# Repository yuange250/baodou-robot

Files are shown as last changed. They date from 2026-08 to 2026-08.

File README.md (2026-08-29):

# Brufik in One

Monorepo combining **Brufik hardware/firmware** and **opendesk-service backend**.

> The current Baodou robot runs the ESP32-to-Doubao Realtime direct firmware. See the Chinese [`firmware development and flashing guide`](docs/firmware-development-and-flashing.md) for the source map, local setup, Windows flashing, logs, smoke tests, and Coding Agent handoff notes.

| Directory | Description |
|---|---|
| [`hardware/`](hardware/) | ESP32S3 firmware, mechanical assets, PCB rebuild files, flash scripts |
| [`service/`](service/) | Voice backend: VAD → ASR → LLM → TTS, WebSocket `/asr_chat`, web console |

## Quick start

### 1. Backend (service)

```bash
cd service
cp .env.example .env
# Edit .env — set LLM_API_KEY
chmod +x start.sh
./start.sh
```

Web console: `http://<host>:5050/` · Device WS: `ws://<host>:9000/asr_chat`

See [`service/README.md`](service/README.md).

### 2. Firmware (hardware)

```bash
cd hardware
# Copy firmware/deskbot_local_config.example.h to the ignored
# firmware/deskbot_local_config.h, then fill in local values.
./flash_rom.sh all
```

See [`hardware/README.md`](hardware/README.md) and [`hardware/README_zh.md`](hardware/README_zh.md).

For direct Realtime firmware, local credentials, Windows flashing, and safe GitHub publishing, see
[`docs/local-config-and-github.md`](docs/local-config-and-github.md).

For the current firmware architecture and complete edit/build/flash workflow, see
[`docs/firmware-development-and-flashing.md`](docs/firmware-development-and-flashing.md).

## License

- **Hardware** ([`hardware/mechanical/`](hardware/mechanical/)): CERN-OHL-S-2.0
- **Firmware** ([`hardware/firmware/`](hardware/firmware/)): GPL-3.0
- **Service** ([`service/`](service/)): GPL-3.0

See respective `LICENSE` files in each subtree.

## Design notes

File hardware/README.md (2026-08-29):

# Brufik

[中文](README_zh.md) | English

**Hardware in this repository is under [CERN-OHL-S-2.0](mechanical/LICENSE); software is under [GPL-3.0](firmware/LICENSE).**

**Brufik** is an open-source deskbot on **Seeed XIAO ESP32S3 Sense**. Backend: [open-deskbot-service](https://github.com/OpenDeskBot/open-deskbot-service).

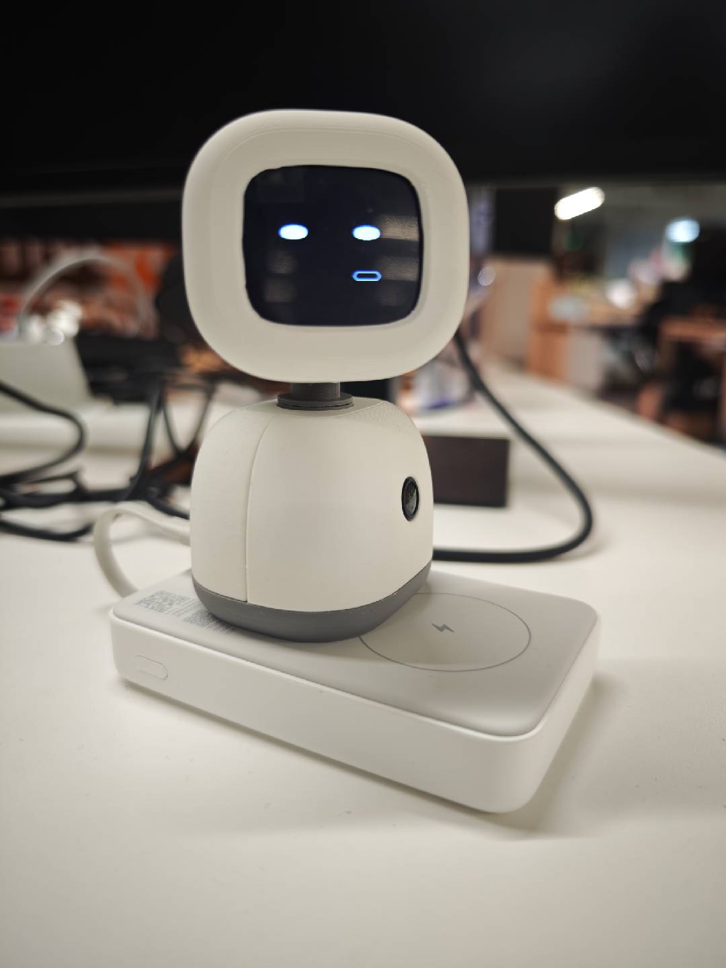
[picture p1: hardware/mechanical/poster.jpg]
Brufik deskbot — assembled unit


---

## 1. Out of the box

1. Copy [`firmware/deskbot_local_config.example.h`](firmware/deskbot_local_config.example.h) to the ignored `firmware/deskbot_local_config.h`, then set the local Wi-Fi values.
2. Power on — the device joins that WiFi and talks to your backend.
3. To use another SSID: power on the deskbot, join AP **`Deskbot_Rom`**, then open the address shown on the screen, usually **`http://192.168.4.1/`**. The onboarding page lets you pick or type your home WiFi and save it. For compile-time defaults, edit only the ignored `deskbot_local_config.h`.

---

## 2. Developers

The current Baodou unit uses the ESP32-to-Doubao Realtime direct firmware. On Windows, use `scripts/build_direct.ps1` so the ignored local Realtime/Ark credentials are injected at build time. See the Chinese [`firmware development and flashing guide`](../docs/firmware-development-and-flashing.md) for the complete workflow.

Create the ignored `firmware/deskbot_local_config.h` from its example, then:

```bash
./flash_rom.sh all
```

Deploy [open-deskbot-service](https://github.com/OpenDeskBot/open-deskbot-service). Firmware WebSocket: **`/asr_chat`**.

Optional debug: `http://<device-ip>/` for a local camera page.

---

## 3. DIY assembly

| Part | Notes | Search terms |
|---|---|---|
| MCU | Camera module + **onboard mic** on the Sense board (**no extra purchase**) | Seeed XIAO ESP32S3 **Sense** |
| Lens | For **OV2640**; **120°** wide angle; **same-plane** (not off-axis); **25 mm** length | `OV2640 lens 120° same plane 25mm` |
| LCD | 1.83" SPI ST7789 240×284 | Waveshare 1.83 LCD Rev2 |
| Servos | **Large + small**; pan = **2g micro servo**, tilt = larger servo | `2g servo`, `SG90` / `9g servo` |
| Amp | I2S | MAX98357A |
| Speaker | **2011** type | `2011 speaker`, `8Ω 2011` |
| Power | 5V ≥1A for servos | — |
| PCB | This repo includes an extension **PCB** for easier wiring; **hand-wiring without the PCB also works** | — |

### Assembly guide & reference photos

- **Step-by-step manual:** [`mechanical/说明书1.02PDF.pdf`](mechanical/说明书1.02PDF.pdf)
- **All parts laid out:** [`mechanical/parts-overview.png`](mechanical/parts-overview.png)
- **Core assembly done (shell not installed):** [`mechanical/assembly-without-shell.png`](mechanical/assembly-without-shell.png)
- **Side view without shell:** [`mechanical/assembly-side-no-shell.png`](mechanical/assembly-side-no-shell.png)

### Wiring (XIAO pad → device)

> Schematic **IO8 / IO3** = **GPIO numbers**, not silkscreen D8/D3.

| Device | Signals | XIAO pads |
|---|---|---|
| LCD SPI | MOSI/CLK/CS/DC | D10 / D8 / D1 / D2 |
| Servo X (pan) | PWM | **D9 / GPIO8** (2g; firmware applies 2:1 gain and tool-layer mirroring) |
| Servo Y (tilt) | PWM | **D3 / GPIO4** (large; lower logical values tilt upward) |
| MAX98357 | DIN/BCLK/LRC | D0 / D5 / D4 → 2011 speaker |
| Mic | PDM | **Onboard** (ESP32S3 Sense) |

Details: [`firmware/deskbot_config.h`](firmware/deskbot_config.h).

---

## License

| Scope | License | File |
|---|---|---|
| Hardware ([`mechanical/`](mechanical/)) | CERN-OHL-S-2.0 | [`mechanical/LICENSE`](mechanical/LICENSE) |
| Software ([`firmware/`](firmware/) etc.) | GNU GPL v3.0 | [`firmware/LICENSE`](firmware/LICENSE) |

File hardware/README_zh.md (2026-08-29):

# Brufik

[English](README.md)

**本仓库中的硬件设计部分遵循 [CERN-OHL-S-2.0](mechanical/LICENSE)，软件部分遵循 [GPL-3.0](firmware/LICENSE)。**

**Brufik** 是一款开源桌面机器人：Seeed XIAO ESP32S3 Sense + 屏 + 舵机 + 麦 + 喇叭。语音与画面走自建后台 [open-deskbot-service](https://github.com/OpenDeskBot/open-deskbot-service)。

Brufik 桌面机器人 — 组装完成实物

---

## 一、开箱即用

1. 复制 [`firmware/deskbot_local_config.example.h`](firmware/deskbot_local_config.example.h) 为被忽略的 `firmware/deskbot_local_config.h`，在其中填写本机 Wi‑Fi。
2. 给机器人上电，自动连上该 WiFi 并访问语音后台后即可使用（对话、表情、头部动作）。
3. 若需改用家里 WiFi：给小歪上电后按屏幕提示连接热点 **`Deskbot_Rom`**，浏览器打开屏幕上的地址（通常是 **`http://192.168.4.1/`**），按 onboarding 页面选择家里的 WiFi 并保存；编译期默认值只修改被忽略的 `deskbot_local_config.h`。

---

## 二、本地开发者

**需要：** USB、[PlatformIO](https://platformio.org/)，串口 `dialout` 权限。

当前包逗实机使用 ESP32 直连豆包 Realtime 版本。Windows 下应优先使用 `scripts/build_direct.ps1` 注入本地 Realtime/Ark 凭证；完整修改、烧录、日志和冒烟测试流程见 [`../docs/firmware-development-and-flashing.md`](../docs/firmware-development-and-flashing.md)。

烧录前从示例复制并编辑被忽略的 `firmware/deskbot_local_config.h`：`WIFI_DEFAULT_*`、`DESKBOT_WS_HOST`、`DESKBOT_WS_PORT`。

```bash
git clone https://github.com/OpenDeskBot/open-deskbot-hardware.git
cd open-deskbot-hardware
./flash_rom.sh all
```

| 命令 | 说明 |
|---|---|
| `./flash_rom.sh build` | 编译 |
| `./flash_rom.sh upload [端口]` | 烧录 |
| `./flash_rom.sh log [端口]` | 串口监视 |
| `./flash_rom.sh all [端口]` | 烧录 + 监视 |

后台部署见 [open-deskbot-service](https://github.com/OpenDeskBot/open-deskbot-service)。固件 WebSocket：**`/asr_chat`**。

调试：连上 WiFi 后浏览器可开 `http://<设备IP>/` 看摄像头（可选）。

---

## 三、自行组装

### 元器件与采购关键词

| 部件 | 说明 | 搜索关键词（淘宝/嘉立创等） |
|---|---|---|
| 主控 | 带摄像头模组 + **板载麦克风**（Sense 扩展板上，**无需另购**） | `Seeed XIAO ESP32S3 Sense`、`Seeed Studio XIAO ESP32S3 Sense` |
| 镜头 | **OV2640** 用；广角 **120°**；**同面**（勿买异面）；长度 **25 mm** | `OV2640 镜头 120度 同面 25mm` |
| 屏幕 | 1.83 寸 SPI，**ST7789** 240×284 | `微雪 1.83寸 LCD`、`Waveshare 1.83 LCD Rev2`、`ST7789 240x284` |
| 舵机 | **一大一小**：俯仰用大舵机，水平用 **2g 舵机** | `2g 舵机`、`微型舵机 2g`；大舵机可用 `SG90` / `9g 舵机` 等 |
| 功放 | I2S | `MAX98357A`、`MAX98357 模块` |
| 喇叭 | **2011** 腔体喇叭 | `喇叭 2011`、`2011 喇叭`、`8Ω 2011 扬声器` |
| 杜邦线 / 细线 | 信号与电源 | `杜邦线`、`硅胶线 26AWG` |
| 电源 | 5V 给舵机（≥1A），3.3V 给板子/屏 | `5V 1A 电源模块`、`USB 5V` |
| PCB | 本项目提供一块扩展 **PCB**，可简化接线；**不用 PCB 也可自行飞线焊接** | — |

### 组装说明与参考图

- **图文说明书：** [`mechanical/说明书1.02PDF.pdf`](mechanical/说明书1.02PDF.pdf)
- **零件全图：** [`mechanical/parts-overview.png`](mechanical/parts-overview.png)
- **基本组装完成（未装外壳）：** [`mechanical/assembly-without-shell.png`](mechanical/assembly-without-shell.png)
- **未装外壳侧面：** [`mechanical/assembly-side-no-shell.png`](mechanical/assembly-side-no-shell.png)

### 接线（XIAO 丝印 → 外设）

> 微雪图纸上的 **IO8 / IO3** 指 **ESP32 GPIO 号**，不是丝印 **D8 / D3**。

| 外设 | 信号 | 接 XIAO 焊盘 | 备注 |
|---|---|---|---|
| **LCD** | MOSI / SCK / CS / DC | **D10 / D8 / D1 / D2** | SPI |
| **舵机 左右 (X)** | PWM | **D9 / GPIO8** | 小 2g 舵机；当前固件含 2:1 增益与工具层镜像 |
| **舵机 上下 (Y)** | PWM | **D3 / GPIO4** | 大舵机；数值减小为抬头 |
| **MAX98357** | DIN / BCLK / LRC | **D0 / D5 / D4** | I2S → 2011 喇叭 |
| **麦克风** | PDM | **板载**（ESP32S3 Sense 主板上） | 无需外接 INMP441 |
| **舵机电源** | 5V / GND | 独立 5V≥1A | 与逻辑共地 |

引脚宏定义见 [`firmware/deskbot_config.h`](firmware/deskbot_config.h) 硬件段。组装完成后按第二节烧录、配网。

---

## 许可证

| 范围 | 协议 | 文件 |
|---|---|---|
| 硬件设计（[`mechanical/`](mechanical/)） | CERN-OHL-S-2.0 | [`mechanical/LICENSE`](mechanical/LICENSE) |
| 软件（[`firmware/`](firmware/) 等） | GNU GPL v3.0 | [`firmware/LICENSE`](firmware/LICENSE) |

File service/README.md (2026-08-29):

# opendesk-service

ESP32 桌面机器人后端：设备上传语音（可选摄像头），服务端完成 **VAD → ASR → LLM → TTS**，经 **pb** 协议下发 PCM、屏幕动画与舵机指令。

**License:** [GPL-3.0](LICENSE)

---

## 最快部署（3 步）

**环境：** Ubuntu 22.04 / 24.04（或 macOS / Windows Git Bash）、Python **3.11**、`ffmpeg`、可访问外网（首次下载模型与 pip 包）。

```bash
# 1. 系统依赖（Ubuntu）
sudo apt update
sudo apt install -y python3.11 python3.11-venv python3.11-dev ffmpeg curl git

# 2. 配置大模型 Key（必填）
cd opendesk-service
cp .env.example .env
# 编辑 .env，填写 LLM_API_KEY=sk-...

# 3. 一键启动（自动建 venv、下载模型、起主服务 + Web 控制台）
chmod +x start.sh
./start.sh
```

首次启动约需数分钟（ASR 模型约 900MB）。**第二次及以后**若 `.venv` 已完整，直接 `./start.sh` 会自动跳过 pip 安装；也可显式：

```bash
SKIP_SETUP=1 ./start.sh
# 或
FAST_START=1 ./start.sh
```

| 服务 | 地址 | 用途 |
|---|---|---|
| **Web 控制台** | `http://<本机IP>:5050/` | 注册登录、设备与 API Key、定时任务、记忆等 |
| **设备 WebSocket** | `ws://<本机IP>:9000/asr_chat?device_id=<id>&api_key=<key>` | ESP32 语音对话主链路 |

启动后终端会打印**免费体验 API Key** 路径：`data/.free_api_key`（前缀 `odk_free_`，每日 1GB 配额）。

---

## 快速使用

### 1. 打开控制台

浏览器访问 `http://<本机IP>:5050/` → **注册**账号 → 登录进入工作台。

### 2. 获取 API Key

**账号设置** 中创建 API Key，或直接使用首次启动生成的 `data/.free_api_key`。

### 3. 绑定设备

**我的设备** 中添加 `device_id`（与固件一致，如 `deskbot_e8f60a8cf9b0`）。后续管理定时任务、记忆、人脸档案时需先**选择设备**。

### 4. 连接设备对话

固件连接：

```
ws://<本机IP>:9000/asr_chat?device_id=<你的device_id>&api_key=<你的key>
```

说话后发送 `flush`，服务端识别 → 调用 LLM → TTS → pb 下行播放。

### 5. 无硬件时本地试跑

```bash
source .venv/bin/activate
python tools/test_client.py \
  --ws-url "ws://127.0.0.1:9000/asr_chat?device_id=deskbot_dev&api_key=<key>" \
  --input-wav demo_16k_mono.wav
```

WAV 须 **16 kHz / mono / s16le**。麦克风实时测试见 [tools/README.md](tools/README.md)。

### 6. 控制台常用功能

| 菜单 | 说明 |
|---|---|
| 工作台 | 用量概览与快捷入口 |
| 我的设备 | 绑定 / 切换 `device_id` |
| 定时任务 | 查看 LLM 创建的 cron 任务（北京时间），可删除 |
| 记忆 | 按设备管理长期记忆（注入 LLM） |
| 人脸识别 | 按设备查看人脸档案 |
| 用量看板 | 按 Key / 设备查看 ASR、人脸、LLM、TTS 字节统计 |
| 调试台 | 设备在线、LLM 试聊、豆包 TTS、流水线等 |

语音对话中，LLM 可通过工具创建定时提醒（`schedule_task`）、读写设备临时文件、联网搜索等，详见 [docs/SERVER.md](docs/SERVER.md)。

---

## 与 ESP32 的交互（概要）

单条 WebSocket：`/asr_chat?device_id=<id>&api_key=<key>`（也可用 Header `X-API-Key`）。上行、下行均采用 **「JSON + 紧随一条 binary」**，长度由 **`next_bin_len`** 声明，**不用 base64**。

```
┌──────── ESP32 ────────┐                    ┌──── deskbot-server ────┐
│ 麦克风 Opus/PCM       │  audio + binary    │ VAD → FunASR → 文本     │
│ 可选 JPEG             │  camera_frame      │ → DashScope LLM + tools │
│ flush / pb_ack        │ ─────────────────► │ → 豆包 TTS + 音素口型   │
│                       │                    │ → 组 pb + PCM           │
│ 播放 PCM + 画屏       │  pb_* + binary     │                         │
│ 舵机 / 音量 / 帧率    │ ◄───────────────── │                         │
└───────────────────────┘                    └─────────────────────────┘
```

TTS 使用火山引擎豆包（`tts.provider: doubao`），凭证配置见 `.env` 与调试台「TTS 调试」。

### 上行（设备 → 服务端）

| JSON `type` | binary | 说明 |
|---|---|---|
| `audio` + `next_bin_len` | Opus 或 PCM | 语音流；段结束发 `flush` 触发识别与回复 |
| `camera_frame` + `next_bin_len` | JPEG | 可选；人脸检测与调试预览 |
| `pb_ack` | 无 | 播放缓冲回压 |
| `ping` | 无 | 保活 |

### 下行（服务端 → 设备）

默认 **`asr_chat_device_pb_only: true`**：只处理 **`pb_start` / `pb_chunk` / `pb_end` / `pb_single`**，以及紧随的 **s16le PCM**（24 kHz mono）。

完整字段见 **[docs/esp32_pb_protocol.md](docs/esp32_pb_protocol.md)**。

### 固件要点

1. URL 必须带稳定 **`device_id`** 与有效 **`api_key`**。
2. JSON 与 binary **严格成对、顺序发送**。
3. 周期性 **`pb_ack`** 做播放回压。

---

## 数据与目录

| 路径 | 说明 |
|---|---|
| `data/opendesk.db` | 用户、API Key、设备绑定、定时任务（SQLite） |
| `data/.free_api_key` | 免费体验 Key（勿提交 Git） |
| `data/device/{device_id}/` | 按设备隔离的配置、session、记忆等（**不入 Git**） |
| `data/llm_system.txt` | 全局 LLM 人设模板（新设备首次使用时复制） |

---

## 文档索引

| 文档 | 内容 |
|---|---|
| [docs/api_interfaces.md](docs/api_interfaces.md) | Web 控制台、deskbot 设备服务、TTS 侧车接口清单 |
| [docs/esp32_pb_protocol.md](docs/esp32_pb_protocol.md) | ESP32 通信、鉴权、pb 协议 |
| [docs/SERVER.md](docs/SERVER.md) | 主服务 API、配置、LLM 工具 |
| [docs/ARCHITECTURE.md](docs/ARCHITECTURE.md) | 代码分层与模块 |
| [tools/README.md](tools/README.md) | 本地联调脚本 |
| [docs/README.md](docs/README.md) | 文档目录 |

[CONTRIBUTING.md](CONTRIBUTING.md) · [SECURITY.md](SECURITY.md)

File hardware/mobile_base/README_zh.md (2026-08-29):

# Brufik × N3 移动底座 Rev 0.1

这套设计让现有 Brufik 上半身保持不动，在下方增加淘宝 N3 三轮全向底盘。
新增控制板独立负责三只 N20 电机、触摸输入和 5V 上半身供电，通过 UART 与
现有主板通信。

## 目录

- `mechanical/`：参数化外壳、转接座、触摸片支架和孔位验证片。
- `pcb/`：KiCad 4 层底盘控制板、BOM、接口表与嘉立创生产文件。

## 先做什么

1. 先打印 `mechanical/export/N3_58x49_fit_jig_v0_1.stl`。
2. 到货后确认 58 × 49 mm 孔位以及三个轮心到中心的距离。
3. 用限流电源手焊验证一块 PCB，再打印整套上盖。
4. 6V N20 初次测试时把最大 PWM 限为 70%，并让 J2 总开关随手可断电。

## 设计边界

- 外壳按卖家公布的 160 × 150 × 65 mm 整机尺寸和 50 mm 全向轮建立。
- 卖家没有给轮心精确坐标；当前模型暂按 57 mm 轮心半径，必须由实物复核。
- PCB 为 92 × 74 mm，安装孔仍是 N3 标准 58 × 49 mm。
- PCB 已通过 KiCad DRC（0 违规、0 未连接）；Gerber 可用于裸板试产。
- PCBA 仍需要在嘉立创逐项确认 LCSC 料号和贴装方向。

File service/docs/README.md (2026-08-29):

# 文档目录

本仓库文档与当前实现对齐，入口为根目录 [README.md](../README.md)。

## 协议与设备

| 文档 | 内容 |
|---|---|
| [api_interfaces.md](./api_interfaces.md) | Web 控制台、deskbot 设备服务、TTS 侧车接口清单 |
| [esp32_pb_protocol.md](./esp32_pb_protocol.md) | ESP32 WebSocket 鉴权、上行 / 下行、pb v2 图元与表情 |

## 服务

| 文档 | 内容 |
|---|---|
| [SERVER.md](./SERVER.md) | 主服务：端口、控制台、LLM 工具、豆包 TTS 配置 |
| [ARCHITECTURE.md](./ARCHITECTURE.md) | 代码分层、对话与定时任务链路 |

## 联调工具

| 文档 | 内容 |
|---|---|
| [../tools/README.md](../tools/README.md) | WAV / 麦克风 / 相机测试客户端 |

## 协作与安全

| 文档 | 内容 |
|---|---|
| [../CONTRIBUTING.md](../CONTRIBUTING.md) | 贡献流程与测试 |
| [../SECURITY.md](../SECURITY.md) | 密钥、鉴权与部署安全 |

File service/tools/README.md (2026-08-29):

# 本地调试工具

在 `.venv` 激活后运行。WebSocket URL **须带 `device_id` 与 `api_key`**（可用 `data/.free_api_key` 中的免费 Key）。

```bash
source .venv/bin/activate
KEY="odk_free_xxxx"   # 替换为实际 Key

# 推送 wav 测 /asr_chat 全链路
python tools/test_client.py \
  --ws-url "ws://127.0.0.1:9000/asr_chat?device_id=deskbot_dev&api_key=${KEY}" \
  --input-wav demo_16k_mono.wav

# 本机麦克风
python tools/live_mic_client.py \
  --ws-url "ws://127.0.0.1:9000/asr_chat?device_id=deskbot_dev&api_key=${KEY}"

# 推图片测 camera_frame
python tools/camera_test_client.py \
  --ws-url "ws://127.0.0.1:9000/asr_chat?device_id=deskbot_dev&api_key=${KEY}" \
  --image-dir ./samples

# 设备-服务端网络连通性 / 并发 / PB 延迟（须真实设备在线）
python tools/network_connectivity_test.py \
  --device-id deskbot_e8f60a8cf9b0 \
  --base-url http://127.0.0.1:9000 \
  --concurrent-sec 20
```

WAV 须 **16 kHz / mono / s16le**。

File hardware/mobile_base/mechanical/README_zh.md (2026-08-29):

# Brufik × N3 移动底座外壳

本目录是针对淘宝 N3 三轮全向底盘的参数化机械设计。设计目标是保留现有
Brufik 机身和内部机构，只在下方增加可拆卸移动底座。

## 设计组成

- `N3_upper_cowl_v0_1`：覆盖上层亚克力板和电子仓的低矮外壳，带三个轮拱。
- `Brufik_to_N3_adapter_v0_1`：现有机身与 N3 的转接座。
- `N3_58x49_fit_jig_v0_1`：先打印的孔位验证片。
- `Head_touch_electrode_holder_v0_1`：粘在头壳内侧的触摸电极固定片。
- `Brufik_N3_mobile_base_v0_1.step`：装配参考模型。

## 打印与验证顺序

1. 先打印 `N3_58x49_fit_jig_v0_1.stl`，确认卖家所说的 58 × 49 mm 孔距。
2. 用 M3 螺钉检查四个长圆孔均可自由通过。
3. 核对三个轮心到中心的实际距离。脚本暂按 57 mm 设计。
4. 孔距正确后再打印转接座和上盖。

推荐参数：0.4 mm 喷嘴、0.20 mm 层高、4 道墙、20% Gyroid 填充。转接座和
孔位片不需要支撑；上盖大平面朝向打印板，轮拱区域使用树状支撑。

## 当前需要实物复核的参数

卖家图片只给出了整体尺寸和标准孔位，没有给出三个轮心坐标。所有待复核尺寸
集中在 `generate_cad.py` 的 `N3Dimensions` 中，底盘到货后只需修改参数并重新
执行脚本即可生成全部 STL/STEP。

生成命令：

```powershell
$env:PYTHONPATH='C:\Users\Chen\AppData\Local\Temp\codex-brufik-cadquery'
python .\generate_cad.py
```

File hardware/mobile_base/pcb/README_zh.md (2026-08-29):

# Brufik N3 移动底盘控制板

这是与现有 Brufik 主板并行工作的底盘副板，不替换已经调通的屏幕、音频、
摄像头和舵机主板。

## 主要功能

- XIAO ESP32-C3 独立执行三轮全向运动控制。
- 两颗 DRV8833 驱动三只 N20 电机。
- 三路 0.20Ω 电流采样电阻将斩波电流设在约 1A。
- 2S 受保护锂电池输入，5A 自恢复保险和外接总开关。
- TPS54302 产生 5V/3A，给现有机器人上半身供电。
- 一个四针上半身接口：5V、GND、UART TX、UART RX。
- 一个三针数字触摸接口。
- J2 外接自锁总开关，既是电源开关也是机械急停。

## 供电边界

电机 VM 直接来自 2S 电池。对于套件内常见的 6V N20，固件必须把最大 PWM
限制在 70%，并保留约 1A 的硬件限流。若卖家提供 9V N20，则可将最大 PWM
上调，但仍需测量堵转电流和驱动温度。

J2 必须连接自锁开关；台架调试时可以暂时用跳线帽短接。连接 USB 给底盘 XIAO
刷机前，先关闭电池总开关并拔掉 J6 上半身接口，避免 USB 5V、板载 5V 与上半身
USB 互相反向供电。

## PCB 规格

- 外形：92 × 74 mm，四角倒角。
- 安装孔：58 × 49 mm，M3。
- 4 层板：F.Cu 信号/功率、In1.GND、In2.VBAT（局部 SLEEP 走线）、B.Cu 信号。
- 推荐：1.6 mm、1 oz 外层/内层铜、HASL-LF 或 ENIG。

## 当前验证状态

- KiCad 10 DRC：0 违规。
- 未连接网络：0。
- `production/BrufikMobileBase_gerbers.zip` 可直接用于裸板下单。
- BOM 与贴片坐标已经导出，但不是一键 PCBA 文件；下贴片单前仍需在嘉立创
  核对每个 LCSC 编号、封装方向和缺料替代。

## 下单前仍需实物确认

这是根据卖家尺寸和原厂数据手册生成的 Rev 0.1 工程。底盘到货后，仍需确认：

1. N20 电机额定电压与堵转电流；
2. 58 × 49 mm 孔距；
3. 电池包是否自带 2S BMS；
4. 嘉立创元件库中的 DRV8833PWPR、TPS54302DDCR 和连接器封装。

裸板可以按生产包下单；首次只下 5 片并手焊 1 片验证。开关降压部分应按 TI
推荐布局复核输入电容、SW 节点、L1 和输出电容，通电前先用限流电源测试。

生成与检查：

```powershell
& 'C:\Users\Chen\AppData\Local\Programs\KiCad\10.0\bin\python.exe' .\generate_pcb.py
powershell.exe -NoProfile -ExecutionPolicy Bypass -File .\export_production.ps1
```

原厂参考：

- TI DRV8833 datasheet: https://www.ti.com/lit/ds/symlink/drv8833.pdf
- TI TPS54302 datasheet: https://www.ti.com/lit/ds/symlink/tps54302.pdf

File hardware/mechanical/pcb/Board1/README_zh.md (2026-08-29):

# Board1 原理图（重建版）

本目录提供 **Brufik 转接板 Board1 / PCB1** 的连接关系重建文件。  
原始 PCB 在嘉立创 EDA 中设计（BOM 导出者 `jlceda`，2026-06-12），但仓库目前只包含 BOM 与贴片坐标，**未包含原始 `.epro` 工程**。

## 文件说明

| 文件 | 用途 |
|---|---|
| **`Board1_kicad.zip`** | **可直接导入嘉立创 EDA 的 KiCad 工程压缩包（推荐）** |
| `Board1.kicad_pro` / `.kicad_sch` / `.kicad_pcb` | KiCad 工程（**v2.1 PCB 已含元件布局**） |
| `generate_kicad.py` | 重新生成上述 KiCad 文件的脚本 |
| `Board1_schematic.svg` | 可视化原理图/框图，可导入嘉立创 EDA 作参考底图 |
| `Board1_pinout.csv` | 逐引脚网表，手工画原理图时对照 |
| `Board1.net` | KiCad 风格网表，可用于核对网络 |
| `../BOM_Board1_PCB1_2026-06-12.xlsx` | 官方 BOM（LCSC 料号/封装） |
| `../PickAndPlace_PCB1_2026_06_12.xlsx` | 官方贴片坐标 |

## 导入嘉立创 EDA 的推荐步骤

### 方案 A：你有原始嘉立创账号工程（最佳）

若 PCB 是你或团队在嘉立创 EDA 里画的：

1. 登录 [嘉立创EDA 标准版](https://lceda.cn/editor) 或 [专业版](https://pro.lceda.cn/editor)
2. 打开对应工程 → **个人中心 → 工程 → 工程高级设置 → 下载工程**
3. 得到 `.epro` 或 JSON 压缩包，直接在编辑器中打开即可

> BOM 里的 `docProps/custom.xml` 含工程指纹，说明原始文件来自嘉立创 EDA。

### 方案 B：在嘉立创 EDA 中按 BOM 重建原理图（本仓库无原工程时）

转接板元件少，建议 **30–60 分钟手工重建**，比格式转换更可靠。

#### 1. 新建工程

- 标准版：<https://lceda.cn/editor> → 新建 → 原理图 + PCB
- 专业版：<https://pro.lceda.cn/editor> → 新建工程

#### 2. 放置元件（与 BOM 一致）

在 LCSC 库中搜索并放置：

| 位号 | 型号/关键词 | 封装 |
|---|---|---|
| USB1 | `TYPE-C 6P(073)` / C668623 | TYPE-C-SMD_TYPE-C-6P-073 |
| 1K1, 5.1k | `0805 5.1k` / C27834 | R0805 |
| H3, H4 | `PZ254V-11-07P` / C492406 | HDR-TH_7P-P2.54-V-M |
| vin | `PZ254R-11-07P` / C492415 | HDR-TH_7P-P2.54-H-M-W10.4 |
| vcc | `ZX-MX1.25-8PLT` / C19272385 | CONN-SMD_8P-P1.25 |
| X舵机 | `PZ254R-11-03P` / C492411 | HDR-TH_3P-P2.54-H-M-W10.4 |
| Y舵机 | `PZ254V-11-03P` / C2937625 | HDR-TH_3P-P2.54-V-M |

也可：**文件 → 导入 → BOM**，直接导入 `BOM_Board1_PCB1_2026-06-12.xlsx`（若编辑器支持），再补连线。

#### 3. 按网表连线

打开 `Board1_pinout.csv`，逐网络连接。核心网络：

```
+5V:  USB1.VBUS → H4-5V → X舵机-2 → Y舵机-2
GND:  所有连接器 GND、CC 下拉电阻另一端
+3V3: H4-3V3 → vin-1 → vcc-1
I2S:  H3-D0/D5/D4 → vin-3/4/5
LCD:  H3-D1/D2 + H4-D8/D10 → vcc-5/6/4/3
舵机: H4-D6/D7 → Y舵机-3 / X舵机-3
喇叭: vcc-7/8 → vin-6/7 → MAX98357 模块
USB CC: CC1→1K1→GND, CC2→5.1k→GND
```

#### 4. 导入参考底图（可选）

- **标准版**：PCB 编辑器 → **工具 → 导入图像** → 选 `Board1_schematic.svg`，缩小透明度作对照
- **专业版**：PCB → **放置 → 图片** 或导入 DXF/SVG 参考层

#### 5. 原理图转 PCB

- 菜单：**设计 → 原理图转 PCB**
- 检查封装映射无误后生成 PCB

#### 6. 对齐已有贴片坐标

若需与官方 PCB 布局一致：

1. PCB 中 **文件 → 导入 → 坐标文件**（或手动对照）
2. 导入 `PickAndPlace_PCB1_2026_06_12.xlsx`
3. 逐位号核对 Mid X/Y、Rotation、Layer

#### 7. 设计规则检查

- 原理图：**设计 → 电气规则检查 (ERC)**
- PCB：**设计 → 设计规则检查 (DRC)**
- 对照 `Board1_pinout.csv` 与 `firmware/deskbot_config.h` 引脚定义

### 方案 C：导入本目录 KiCad 工程（最快）

已生成完整 KiCad 工程，可直接导入嘉立创 EDA：

#### 嘉立创 EDA 标准版

1. 打开 <https://lceda.cn/editor>
2. **文件 → 导入 → KiCad**
3. 选择 `Board1_kicad.zip`（或整个 `Board1/` 文件夹打 ZIP）
4. 等待解析完成，打开原理图核对网络
5. 打开 **PCB 编辑器** — v2.1 已按官方 PickAndPlace 放置 9 个元件（约 36×44mm 板框）
6. 若 PCB 仍为空，重新导入最新 `Board1_kicad.zip`（勿用旧版）
7. **设计 → 更新 PCB** 同步原理图网络后 **自行布线**（无官方走线）

#### 嘉立创 EDA 专业版

1. 打开 <https://pro.lceda.cn/editor>
2. **文件 → 导入 → KiCad**（或使用 **格式转换器**）
3. 选择 `Board1_kicad.zip`
4. 核对符号/网络，打开 PCB 查看元件布局（9 个封装 + 板框）
5. **更新 PCB** 同步网络，再布线

#### 用 KiCad 打开（可选）

1. 安装 [KiCad 8+](https://www.kicad.org/download/)
2. 打开 `Board1.kicad_pro`
3. 若提示库缺失，可忽略（符号已内嵌在 `.kicad_sch`）
4. 修改后 **文件 → 归档工程** 再导入嘉立创

> 本 KiCad 工程为 **BOM + 固件引脚反推重建**，非官方 Gerber 源文件。导入后请对照 `Board1_pinout.csv` 做 ERC，并将连接器封装替换为 LCSC 官方 footprint（C668623 等）。

## XIAO 插座引脚对照

```
H3 (7P):  D0  D1  D2  D3  D4  D5  GND
H4 (7P):  5V  3V3 D6  D7  D8  D9  D10
```

丝印与 GPIO 对应见 `firmware/deskbot_config.h`：

- D0=GPIO1 (I2S DIN)
- D1=GPIO2 (LCD CS)
- D2=GPIO3 (LCD DC)
- D4=GPIO5 (I2S LRC)
- D5=GPIO6 (I2S BCLK)
- D6=GPIO43 (Y 舵机)
- D7=GPIO44 (X 舵机)
- D8=GPIO7 (LCD SCK)
- D10=GPIO9 (LCD MOSI)

## 注意事项

1. **SPK+/SPK- 引脚顺序**：本重建依据说明书「头部喇叭线 → 转接板 → 功放板」走线推断；若你手上有已装好的板子，用万用表通断档核对 vcc-7/8 与 vin-6/7 最稳妥。
2. **D3、D9** 在本板未引出到外部连接器，原理图中可悬空或加 NC 标记。
3. 若需下单 PCB，可直接使用官方 Gerber（如后续仓库补充）；本重建版仅供原理图编辑/学习，**不保证与量产 Gerber 逐线一致**。

## 相关文档

- 接线表：[`README_zh.md`](../../../README_zh.md) 第三节
- 组装说明：[`mechanical/说明书1.02PDF.pdf`](../../说明书1.02PDF.pdf)

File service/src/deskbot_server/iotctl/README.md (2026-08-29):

# miot-ctl

轻量米家 IoT 命令行工具，基于 [miloco-miot](https://github.com/XiaoMi/xiaomi-miloco) SDK，**不依赖 Miloco 服务端**。

安装体积约 **50–80 MB**（仅 HTTP 控制所需依赖，无 opencv/onnx/感知模型）。

## 快速开始

```bash
# 1. 安装（自动下载 wheel + 创建虚拟环境）
bash install.sh

# 2. 绑定小米账号
./miot-ctl auth bind

# 授权后浏览器会跳到 https://127.0.0.1/?code=...&state=...
# 页面显示「无法访问」是正常的，复制地址栏完整 URL 执行：
./miot-ctl auth authorize "https://127.0.0.1/?code=...&state=..."

# 3. 列出设备
./miot-ctl device list

# 4. 查看设备能力
./miot-ctl device spec <did>

# 5. 控制设备
./miot-ctl device set <did> on true
./miot-ctl device set <did> brightness 60
./miot-ctl device props <did> brightness

# 6. 调用动作（如音箱播报）
./miot-ctl device action <did> play-text "你好"
```

## 目录结构

```
iotctl/
├── install.sh          # 一键安装
├── miot-ctl            # 启动脚本
├── requirements.txt    # 最小 Python 依赖
├── miot_ctl/           # 工具源码
├── wheels/             # install.sh 下载的 SDK wheel
└── .venv/              # 虚拟环境（install.sh 创建，本地生成）
```

**运行时数据（含 token）不入库**，默认写入：

```
service/data/miot-cli/          # 独立 CLI（auth bind 等）
service/data/device/{id}/miot/  # deskbot 网站 / LLM 按设备绑定
```

上述目录已在 `service/.gitignore` 中忽略，**禁止**提交 `auth.json` 等敏感文件。

## 拷贝到其他机器

整个 `miot-ctl/` 目录可以直接复制走。到新机器后：

```bash
cd miot-ctl
bash install.sh    # 若已带 wheels/ 和 .venv 可跳过，直接 ./miot-ctl
./miot-ctl auth status
```

迁移 CLI 登录态时拷贝 `service/data/miot-cli/`，或在新机器重新 `auth bind`。

也可自定义数据目录：

```bash
export MIOT_CTL_HOME=/path/to/your/data
./miot-ctl device list
```

## 命令参考

### 账号

| 命令 | 说明 |
|---|---|
| `auth bind` | 浏览器授权绑定 |
| `auth authorize <base64>` | 非交互提交授权码 |
| `auth status` | 查看绑定状态 |
| `auth unbind` | 解绑 |

### 设备

| 命令 | 说明 |
|---|---|
| `device list [--online] [--json]` | 设备列表 |
| `device get <did>` | 设备详情 |
| `device spec <did>` | 能力列表 |
| `device set <did> <key> <value>` | 写属性 |
| `device props <did> [key...]` | 读属性 |
| `device action <did> <key> [args...]` | 调用动作 |

`key` 支持：
- `type_name`：如 `on`、`brightness`、`color-temperature`
- `prop.{siid}.{piid}` / `action.{siid}.{aiid}`

`value` 自动推断类型：`true/false/on/off` → 布尔，纯数字 → 数值，其余 → 字符串。

### 场景

| 命令 | 说明 |
|---|---|
| `scene list` | 列出手动场景 |
| `scene run <scene_id>` | 触发场景 |

## 手动安装 wheel

若 `install.sh` 下载失败，可手动放置 wheel：

```bash
# 从 GitHub Release 下载对应平台 wheel，例如：
# miloco_miot-2026.7.3-py3-none-manylinux_2_28_x86_64.whl
mkdir -p wheels
cp /path/to/miloco_miot-*.whl wheels/
bash install.sh
```

## 许可

基于 Xiaomi Miloco / miloco-miot SDK，**仅限非商业用途**。详见上游 [LICENSE.md](https://github.com/XiaoMi/xiaomi-miloco/blob/main/LICENSE.md)。

## 故障排查

| 现象 | 处理 |
|---|---|
| `未绑定小米账号` | 运行 `auth bind` |
| `state 不匹配` | 重新 `auth bind`，不要复用旧授权码 |
| `设备 spec 中未找到` | 先 `device spec <did>` 查正确 key |
| 控制成功但设备无反应 | 看返回 JSON 中 `code` 负值和 `code_msg` |
| 安装慢 | 设置 `export UV_INDEX_URL=https://pypi.tuna.tsinghua.edu.cn/simple` |

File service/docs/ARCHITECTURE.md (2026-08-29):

# deskbot-server 架构（概要）

分层：**ws / web**（协议入口）→ **application**（用例）→ **core**（端口 Protocol）← **infrastructure**（ASR / LLM / TTS 实现）。**pb**、**vision** 不依赖 ws。

## 主链路（语音对话）

```
/asr_chat
  → VAD + FunASR（ChatService.asr）
  → run_chat_turn
      → ensure_active_session（按 device 加载历史）
      → complete_llm_with_tool_loop（多轮 tools，最多 8 轮）
      → TTS phoneme 分片
      → pb.wire 组包
      → DownlinkPort.send_pb_wire
```

摄像头：`camera_frame` + JPEG → `camera_jpeg_pipeline` → 调试订阅 / 人脸跟踪 / 舵机跟随。

## 定时任务

```
ScheduledTaskScheduler（60s 轮询）
  → claim_due_tasks（SQLite scheduled_tasks，东八区 cron）
  → run_chat_turn（reuse_session_id，强制 TTS 提醒）
  → finish_scheduled_task
```

任务由 LLM `schedule_task` 工具创建；**不由服务端从用户话术正则推断**。

## 模块一览

| 目录 / 模块 | 职责 |
|---|---|
| `ws/` | WebSocket 路由、`AsrChatHub`、pb 下行队列、API Key 门禁 |
| `web/` | Flask 控制台（`app_bp` 设备/任务/记忆/人脸，`debug_bp` 调试） |
| `auth/` | 用户注册登录、API Key、设备绑定 |
| `db/` | SQLAlchemy 模型（User、ApiKey、Device、ScheduledTask、UsageDaily） |
| `application/chat_flow.py` | 单轮对话编排（LLM + TTS + pb） |
| `application/llm_tool_loop.py` | LLM 多轮 tool-call |
| `application/llm_tool_runner.py` | 执行 `tools` 指令 |
| `application/scheduled_task_scheduler.py` | 到期任务调度 |
| `scheduled_task_service.py` | cron CRUD、claim / finish |
| `session_store.py` | `data/device/{id}/session/*.json` |
| `device_data.py` | 按设备路径解析配置模板 |
| `memory_store.py` | 长期记忆（全局或设备级 JSON） |
| `pb/` | 表情、口型、舵机、wire 组包 |
| `vision/` | 人脸检测、embedding、跟随 |

## WebSocket

| 路径 | 生产必需 |
|---|---|
| `/asr_chat?device_id=&api_key=` | 是 |
| `/camera_view`、`/device_pipeline` | 否（调试） |

单进程 asyncio；`ChatService`（含 FunASR）全进程共享。重 CPU 走 `asyncio.to_thread`；`config.yaml` 的 `max_concurrent_asr` / `max_concurrent_face_infer` 限流。

## 装配（`main.py`）

```
init_database()
build_chat_service()
AsrChatHub + ScheduledTaskScheduler.start()
websockets.serve(:9000)
```

Web 控制台独立进程：`python -m deskbot_server.web`（`:5050`，`start.sh` 默认拉起）。

## 测试

```bash
source .venv/bin/activate
pytest tests/ -q
```

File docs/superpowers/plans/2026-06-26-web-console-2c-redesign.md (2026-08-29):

# Web 控制台 2C 化改造 Implementation Plan

> **For agentic workers:** REQUIRED SUB-SKILL: Use superpowers:subagent-driven-development (recommended) or superpowers:executing-plans to implement this plan task-by-task. Steps use checkbox (`- [ ]`) syntax for tracking.

**Goal:** 在不改动核心管线/协议/固件的前提下，为 deskbot-server 增加一套消费级（2C）Web 外壳，把「表情」「声音」做成两个核心可玩页面，并把记忆/提醒/人/设备重新包装、把开发者功能收进「高级」。

**Architecture:** 纯前端为主。新增一个 `app2c_bp` 蓝图（仅渲染模板）+ 消费级母版 `base_2c.html` + 主题 `theme_2c.css`，页面用内联 Vue 调用**已存在**的 JSON 接口（`/api/doubao_tts/*`、`/api/face_expr_scenes`、`/app/api/*`）。后端 Phase 1 零新增；Phase 2 可选新增一个极小的 per-device 情绪→场景映射 store。

**Tech Stack:** Flask 3 + Jinja2 + 内联 Vue 3（CDN/vendored）+ 原生 CSS；图标内联 Lucide SVG；pytest。

参考来源：
- 设计 spec：`docs/superpowers/specs/2026-06-26-web-console-2c-redesign-design.md`
- 视觉/标记来源（真实可复制）：`web控制台-2C-原型.html`（仓库根目录）
- 既有测试风格：`service/deskbot-server/tests/test_endpoint_auth.py`

> 所有路径以 `service/deskbot-server/` 为根，除非另写明（如根目录的原型 HTML）。

---

## File Structure

新建：
- `src/deskbot_server/web/static/theme_2c.css` — 消费级主题（从原型 `<style>` 移植）。
- `src/deskbot_server/web/templates/base_2c.html` — 侧边栏外壳 + Lucide 图标宏 + `{% block content %}`。
- `src/deskbot_server/web/templates/app2c/home.html` — 首页「家」。
- `src/deskbot_server/web/templates/app2c/voice.html` — 声音（调既有 `/api/doubao_tts/*`）。
- `src/deskbot_server/web/templates/app2c/expr.html` — 表情（调既有 `/api/face_expr_scenes`）。
- `src/deskbot_server/web/templates/app2c/memories.html` — 它记得的事（调 `/app/api/memories`）。
- `src/deskbot_server/web/templates/app2c/reminders.html` — 提醒（调 `/app/api/scheduled-tasks`）。
- `src/deskbot_server/web/templates/app2c/people.html` — 认识的人（调 `/app/api/face-profiles`）。
- `src/deskbot_server/web/templates/app2c/devices.html` — 我的设备（调 `/app/api/devices`）。
- `src/deskbot_server/web/templates/app2c/advanced.html` — 高级 hub（链接既有页面）。
- `src/deskbot_server/web/blueprints/app2c_bp.py` — 仅渲染上述模板的蓝图。
- `tests/test_app2c_pages.py` — 路由鉴权 + 200 烟雾测试。

修改：
- `src/deskbot_server/web/app.py` — 注册 `app2c_bp`；登录后落地页指向 `/home`。

Phase 2（可选）新建：
- `src/deskbot_server/emotion_expr_map_store.py` — per-device 情绪→场景映射 store。
- `tests/test_emotion_expr_map_store.py` — store 单测。
- 在 `app2c_bp.py` 增加 `GET/POST /api/emotion_expr_map`。
- `tests/test_emotion_expr_map_api.py` — 接口测试。

---

## Phase 0 — 外壳与蓝图

### Task 1: 消费级主题 theme_2c.css

**Files:**
- Create: `src/deskbot_server/web/static/theme_2c.css`

- [ ] **Step 1: 从原型移植样式**

打开仓库根目录 `web控制台-2C-原型.html`，复制其 `<style>…</style>` 标签**内部**的全部 CSS，原样粘贴到 `theme_2c.css`。该 CSS 已包含 `.app/.side/.navi/.stage/.hero/.mini/.vgrid/.vcard/.maprow/.thumb/.toast` 等全部类，且使用 `:root` 变量，无需改动。

- [ ] **Step 2: 校验文件非空且含关键类**

Run: `grep -c -E '\.side|\.navi|\.vgrid|\.thumb' src/deskbot_server/web/static/theme_2c.css`
Expected: 输出 ≥ 4

- [ ] **Step 3: Commit**

```bash
git add src/deskbot_server/web/static/theme_2c.css
git commit -m "feat(web2c): add consumer theme_2c.css ported from prototype"
```

---

### Task 2: 母版 base_2c.html（侧边栏 + Lucide 图标宏）

**Files:**
- Create: `src/deskbot_server/web/templates/base_2c.html`

- [ ] **Step 1: 写母版骨架**

创建 `base_2c.html`，内容如下（侧边栏导航 + 图标宏 + 内容块）。导航项的 `active_nav` 由各页传入。Lucide SVG 路径与原型一致（可从原型 `<nav class="navi">` 与图标处复制；下面已内联常用项）。

```html
{% macro icon(name) -%}
{% if name == 'home' %}<svg viewBox="0 0 24 24"><path d="M3 11l9-8 9 8"/><path d="M5 10v10h14V10"/></svg>
{% elif name == 'expr' %}<svg viewBox="0 0 24 24"><circle cx="12" cy="12" r="9"/><path d="M8.5 14c1 1.3 6 1.3 7 0"/><circle cx="9" cy="10" r="1"/><circle cx="15" cy="10" r="1"/></svg>
{% elif name == 'voice' %}<svg viewBox="0 0 24 24"><path d="M11 5L6 9H3v6h3l5 4z"/><path d="M16 9a4 4 0 010 6"/><path d="M19 6a8 8 0 010 12"/></svg>
{% elif name == 'memory' %}<svg viewBox="0 0 24 24"><path d="M6 3h12a1 1 0 011 1v16l-7-4-7 4V4a1 1 0 011-1z"/></svg>
{% elif name == 'remind' %}<svg viewBox="0 0 24 24"><circle cx="12" cy="12" r="9"/><path d="M12 7v5l3 2"/></svg>
{% elif name == 'people' %}<svg viewBox="0 0 24 24"><circle cx="12" cy="8" r="4"/><path d="M4 20c0-4 4-6 8-6s8 2 8 6"/></svg>
{% elif name == 'device' %}<svg viewBox="0 0 24 24"><rect x="6" y="3" width="12" height="18" rx="2"/><path d="M11 18h2"/></svg>
{% elif name == 'advanced' %}<svg viewBox="0 0 24 24"><circle cx="12" cy="12" r="3"/><path d="M19.4 13a7 7 0 000-2l2-1.5-2-3.4-2.3 1a7 7 0 00-1.7-1L15 3h-4l-.7 2.6a7 7 0 00-1.7 1l-2.3-1-2 3.4L4.6 11a7 7 0 000 2l-2 1.5 2 3.4 2.3-1a7 7 0 001.7 1L11 21h4l.7-2.6a7 7 0 001.7-1l2.3 1 2-3.4z"/></svg>
{% endif %}
{%- endmacro %}
<!DOCTYPE html>
<html lang="zh-CN">
<head>
  <meta charset="UTF-8">
  <meta name="viewport" content="width=device-width, initial-scale=1.0">
  <title>{% block page_title %}小歪 · 我的桌搭子{% endblock %}</title>
  <link rel="stylesheet" href="{{ url_for('static', filename='theme_2c.css') }}">
  {% block extra_head %}{% endblock %}
</head>
<body>
<div class="app">
  <aside class="side">
    <div class="brand"><div class="logo">歪</div><div><b>小歪</b><small>我的桌搭子</small></div></div>
    <nav class="navi">
      <a href="{{ url_for('app2c.home') }}" class="navlink {{ 'on' if active_nav=='home' }}">{{ icon('home') }}家</a>
      <div class="lbl">核心玩法</div>
      <a href="{{ url_for('app2c.expr') }}" class="navlink {{ 'on' if active_nav=='expr' }}">{{ icon('expr') }}表情</a>
      <a href="{{ url_for('app2c.voice') }}" class="navlink {{ 'on' if active_nav=='voice' }}">{{ icon('voice') }}声音</a>
      <div class="lbl">日常</div>
      <a href="{{ url_for('app2c.memories') }}" class="navlink {{ 'on' if active_nav=='memory' }}">{{ icon('memory') }}它记得的事</a>
      <a href="{{ url_for('app2c.reminders') }}" class="navlink {{ 'on' if active_nav=='remind' }}">{{ icon('remind') }}提醒</a>
      <a href="{{ url_for('app2c.people') }}" class="navlink {{ 'on' if active_nav=='people' }}">{{ icon('people') }}认识的人</a>
      <a href="{{ url_for('app2c.devices') }}" class="navlink {{ 'on' if active_nav=='device' }}">{{ icon('device') }}我的设备</a>
      
      <a href="{{ url_for('app2c.advanced') }}" class="navlink {{ 'on' if active_nav=='advanced' }}">{{ icon('advanced') }}高级</a>
    </nav>
    <div class="foot"><div class="userchip"><div class="ua">歪</div><div><b>{{ nav_display_name or '我' }}</b><small>{{ nav_user_email or '' }}</small></div></div></div>
  </aside>
  <main>{% block content %}{% endblock %}</main>
</div>
{% block scripts %}{% endblock %}
</body>
</html>
```

- [ ] **Step 2: 在 theme_2c.css 末尾补 `.navlink` 样式**（原型用 `<button>`，母版用 `<a>`）

把原型中 `.navi button` 的样式追加一份 `.navi .navlink` 等价规则到 `theme_2c.css` 末尾：

```css
.navi .navlink{display:flex;align-items:center;gap:11px;text-decoration:none;
  padding:10px 12px;border-radius:11px;font-size:14px;color:var(--dim);font-weight:600}
.navi .navlink:hover{background:#f6f6fc;color:var(--ink)}
.navi .navlink.on{background:var(--brand-soft);color:var(--brand)}
.navi .navlink svg{width:19px;height:19px;stroke:currentColor;fill:none;stroke-width:1.7;stroke-linecap:round;stroke-linejoin:round;flex:none}
```

- [ ] **Step 3: Commit**

```bash
git add src/deskbot_server/web/templates/base_2c.html src/deskbot_server/web/static/theme_2c.css
git commit -m "feat(web2c): add base_2c shell with sidebar + lucide icon macro"
```

---

### Task 3: app2c 蓝图 + 注册 + 登录落地页

**Files:**
- Create: `src/deskbot_server/web/blueprints/app2c_bp.py`
- Modify: `src/deskbot_server/web/app.py`
- Test: `tests/test_app2c_pages.py`

- [ ] **Step 1: 写失败测试**

```python
# tests/test_app2c_pages.py
from __future__ import annotations

import tempfile
from pathlib import Path

import pytest

@pytest.fixture()
def temp_db(monkeypatch):
    with tempfile.TemporaryDirectory() as tmp:
        db_path = Path(tmp) / "test.db"
        monkeypatch.setenv("DESKBOT_DB_PATH", str(db_path))
        from deskbot_server.db import init_database
        from deskbot_server.db.engine import init_engine, reset_engine

        reset_engine()
        init_engine(db_path)
        init_database()
        yield db_path

def _login_client():
    from deskbot_server.auth.service import create_user
    from deskbot_server.web.app import create_app

    create_user("u2c@example.com", "password1234")
    app = create_app()
    client = app.test_client()
    client.post("/login", data={"email": "u2c@example.com", "password": "password1234"})
    return client

PAGES = ["/home", "/voice", "/expr", "/my/memories", "/my/reminders", "/my/people", "/my/devices", "/advanced"]

def test_2c_pages_redirect_when_anonymous(temp_db):
    from deskbot_server.web.app import create_app

    client = create_app().test_client()
    assert client.get("/home").status_code == 302

@pytest.mark.parametrize("path", PAGES)
def test_2c_pages_render_when_logged_in(temp_db, path):
    resp = _login_client().get(path)
    assert resp.status_code == 200
```

- [ ] **Step 2: 运行确认失败**

Run: `cd service/deskbot-server && python -m pytest tests/test_app2c_pages.py -q`
Expected: FAIL（路由不存在 → 404/302 不匹配，或 import 错误）

- [ ] **Step 3: 写蓝图**

```python
# src/deskbot_server/web/blueprints/app2c_bp.py
from __future__ import annotations

from flask import Blueprint, render_template
from flask_login import login_required

bp = Blueprint("app2c", __name__)

@bp.get("/home")
@login_required
def home():
    return render_template("app2c/home.html", active_nav="home")

@bp.get("/voice")
@login_required
def voice():
    return render_template("app2c/voice.html", active_nav="voice")

@bp.get("/expr")
@login_required
def expr():
    return render_template("app2c/expr.html", active_nav="expr")

@bp.get("/my/memories")
@login_required
def memories():
    return render_template("app2c/memories.html", active_nav="memory")

@bp.get("/my/reminders")
@login_required
def reminders():
    return render_template("app2c/reminders.html", active_nav="remind")

@bp.get("/my/people")
@login_required
def people():
    return render_template("app2c/people.html", active_nav="people")

@bp.get("/my/devices")
@login_required
def devices():
    return render_template("app2c/devices.html", active_nav="device")

@bp.get("/advanced")
@login_required
def advanced():
    return render_template("app2c/advanced.html", active_nav="advanced")
```

- [ ] **Step 4: 创建 8 个最小模板占位**（让路由先能渲染，内容后续任务填充）

为 `templates/app2c/` 下 8 个文件各写最小骨架，例如 `home.html`：

```html
{% extends "base_2c.html" %}
{% block content %}<div class="pagehd"><div><h1>家</h1></div></div>{% endblock %}
```

其余 7 个同样 `{% extends "base_2c.html" %}` + 一个 `<h1>`（标题分别为 表情/声音/它记得的事/提醒/认识的人/我的设备/高级），`active_nav` 已由路由传入。

- [ ] **Step 5: 注册蓝图并把登录落地页指向 /home**

修改 `src/deskbot_server/web/app.py`：

在 `app.register_blueprint(app_bp)` 之后新增一行：

```python
    from deskbot_server.web.blueprints.app2c_bp import bp as app2c_bp
    app.register_blueprint(app2c_bp)
```

并把 `login_manager.login_view` 后续登录成功的跳转指向 `/home`：在 `auth_bp` 登录成功默认 `next` 为 `/home`。**最小改动**：在 `app.py` 的 `require_auth` 中，已登录用户访问 `/` 时重定向到 `app2c.home`：

```python
        if path == "/" and current_user.is_authenticated:
            return redirect(url_for("app2c.home"))
```

（放在 `require_auth` 内、`if path == "/" or path.startswith(...)` 判断**之前**。）

- [ ] **Step 6: 运行测试确认通过**

Run: `cd service/deskbot-server && python -m pytest tests/test_app2c_pages.py -q`
Expected: PASS（9 个用例）

- [ ] **Step 7: Commit**

```bash
git add src/deskbot_server/web/blueprints/app2c_bp.py src/deskbot_server/web/app.py \
        src/deskbot_server/web/templates/app2c/ tests/test_app2c_pages.py
git commit -m "feat(web2c): add app2c blueprint, 8 page routes, smoke tests"
```

---

## Phase 1 — 页面接线（调用既有接口）

> 各页 markup 以根目录 `web控制台-2C-原型.html` 对应 `<section>` 为视觉来源：把该 section 的内部 HTML 放进对应模板的 `{% block content %}`，再按下方把"写死的数据"换成 Vue 拉取既有接口。每个任务完成后手动验收：登录后访问页面、按描述交互。

### Task 4: 首页「家」

**Files:**
- Modify: `src/deskbot_server/web/templates/app2c/home.html`

- [ ] **Step 1: 移植首页 markup**

把原型 `<section class="screen on" id="home">` 的**内部** HTML 复制进 `home.html` 的 `{% block content %}`。把卡片上的 `onclick="go('xxx')"` 改成真实链接：用 `<a href="{{ url_for('app2c.voice') }}">` 等包裹英雄卡/日常卡，或改 `onclick="location.href='…'"`。

- [ ] **Step 2: 手动验收**

启动 web：`cd service/deskbot-server && DESKBOT_WEB_PORT=5050 python -m deskbot_server.web`，登录后访问 `/home`：应见机器人大脸 + 两张英雄卡 + 四个日常入口，点击可跳到对应页面。

- [ ] **Step 3: Commit**

```bash
git add src/deskbot_server/web/templates/app2c/home.html
git commit -m "feat(web2c): home page with hero + daily entries"
```

---

### Task 5: 声音页（调 /api/doubao_tts/*）

**Files:**
- Modify: `src/deskbot_server/web/templates/app2c/voice.html`

接口契约（已存在，见 spec §3）：
- `GET /api/doubao_tts/speakers` → `{ok, speakers:[{label,id,scene,resource_id}]}`
- `GET /api/doubao_tts/config` → `{ok, config:{speaker, ...}}`
- `POST /api/doubao_tts/config` body `{speaker, resource_id}` → 设当前音色
- `POST /api/doubao_tts/synthesize` body `{text, speaker, resource_id}` → `{ok, wav_base64, sample_rate}`

- [ ] **Step 1: 写页面 + Vue 接线**

`voice.html`：

```html
{% extends "base_2c.html" %}
{% block page_title %}声音 · 小歪{% endblock %}
{% block extra_head %}<script src="{{ url_for('static', filename='vendor/vue.global.prod.min.js') }}"></script>{% endblock %}
{% block content %}
<div class="pagehd"><div><h1>声音</h1><p>挑一个喜欢的音色，点试听，满意就设为当前。</p></div></div>
<div id="app">
  <div v-for="(list, scene) in grouped" :key="scene">
    <div class="scene-h">[[ scene ]]</div>
    <div class="vgrid">
      <div class="vcard" :class="{cur: v.id===current}" v-for="v in list" :key="v.id">
        <span class="curtag" v-if="v.id===current">当前</span>
        <b>[[ v.label ]]</b><small>[[ v.scene ]]</small>
        <div class="vbtns">
          <button class="vbtn play" @click="preview(v)">[[ playing===v.id ? '播放中…' : '▶ 试听' ]]</button>
          <button class="vbtn set" @click="setCurrent(v)">[[ v.id===current ? '使用中' : '设为当前' ]]</button>
        </div>
      </div>
    </div>
  </div>
  <div class="slider-card">
    <div class="t"><span>试听音量</span><span>[[ vol ]]</span></div>
    <input type="range" min="0" max="100" v-model.number="vol">
  </div>
  <p class="lead" v-if="msg">[[ msg ]]</p>
</div>
{% endblock %}
{% block scripts %}
<script>
const { createApp } = Vue;
createApp({
  delimiters: ['[[', ']]'],
  data(){ return { speakers:[], current:'', playing:'', vol:80, msg:'' }; },
  computed:{
    grouped(){ const g={}; for(const v of this.speakers){ (g[v.scene||'其他'] ||= []).push(v); } return g; }
  },
  methods:{
    async load(){
      const s = await (await fetch('/api/doubao_tts/speakers')).json();
      this.speakers = s.speakers || [];
      const c = await (await fetch('/api/doubao_tts/config')).json();
      this.current = (c.config && c.config.speaker) || '';
    },
    async setCurrent(v){
      const r = await (await fetch('/api/doubao_tts/config', {method:'POST',
        headers:{'Content-Type':'application/json'},
        body: JSON.stringify({speaker:v.id, resource_id:v.resource_id})})).json();
      if(r.ok){ this.current = v.id; this.msg = '已设为当前音色：'+v.label; }
      else { this.msg = '设置失败：'+(r.error||''); }
    },
    async preview(v){
      this.playing = v.id; this.msg='';
      try{
        const r = await (await fetch('/api/doubao_tts/synthesize', {method:'POST',
          headers:{'Content-Type':'application/json'},
          body: JSON.stringify({text:'你好，我是你的桌搭子小歪。', speaker:v.id, resource_id:v.resource_id})})).json();
        if(r.ok && r.wav_base64){ const a=new Audio('data:audio/wav;base64,'+r.wav_base64); a.volume=this.vol/100; a.play(); }
        else { this.msg='试听失败：'+(r.error||''); }
      } finally { this.playing=''; }
    },
  },
  mounted(){ this.load(); },
}).mount('#app');
</script>
{% endblock %}
```

> 说明：`vue.global.prod.min.js` 已存在于 `static/vendor/`。用 `[[ ]]` 分隔符避免与 Jinja `{{ }}` 冲突。
> 音量：本任务的滑杆控制**试听播放音量**（浏览器端 `Audio.volume`），真实可用。设备「说话音量」的持久化目前无确认的既有写入接口（音量是 LLM 每轮 JSON 字段 / 设备侧），故不在本期内伪造；若后续需要，再确认/新增一个持久化音量接口（与 §7.2 同样的薄接口方式）。

- [ ] **Step 2: 手动验收**

登录后访问 `/voice`：音色按场景分组显示；点「▶ 试听」能听到声音（需 TTS 服务在线 + 已配 `DOUBAO_TTS_API_KEY`）；点「设为当前」后该卡显示「当前」。

- [ ] **Step 3: Commit**

```bash
git add src/deskbot_server/web/templates/app2c/voice.html
git commit -m "feat(web2c): voice page (gallery + preview + set-current) via existing endpoints"
```

---

### Task 6: 表情页（调 /api/face_expr_scenes）

**Files:**
- Modify: `src/deskbot_server/web/templates/app2c/expr.html`

接口契约（已实测确认）：
- `GET /api/face_expr_scenes?device_id=<id>` → `{ok, config:[{name,title,frames:[{ms,elements}]}], exists, file, device_id}`（场景在 **`config`** 键下）
- `POST /api/face_expr_scenes` body `{device_id, scenes:[…]}` → 保存（端点用 `_effective_device_id` 从 body 读 `device_id`，用 `normalize_face_expr_scenes` 从 body 读 `scenes`，两者均兼容）
- 当前设备：`GET /app/api/devices` → `{ok, current_device_id}`

- [ ] **Step 1: 写页面 + Vue（皮肤选择 + 客户端预览 + 保存）**

`expr.html`：

```html
{% extends "base_2c.html" %}
{% block page_title %}表情 · 小歪{% endblock %}
{% block extra_head %}<script src="{{ url_for('static', filename='vendor/vue.global.prod.min.js') }}"></script>{% endblock %}
{% block content %}
<div class="pagehd"><div><h1>表情</h1><p>挑一个面孔风格，右侧大屏实时预览。</p></div>
  <button class="btn primary" @click="save" id="saveBtn">保存表情</button></div>
<div id="app">
  <div class="exprgrid">
    <div class="stage" style="min-height:280px">
      <div class="face" style="width:260px;height:200px">
        <svg width="220" height="170" viewBox="0 0 120 80" v-html="previewSvg"></svg>
      </div>
    </div>
    <div>
      <div class="blocktitle" style="margin-top:0">面孔风格（场景）</div>
      <div class="thumbs">
        <div class="thumb" :class="{sel: i===selected}" v-for="(s,i) in scenes" :key="s.name"
             @click="selected=i">[[ s.title || s.name ]]</div>
      </div>
    </div>
  </div>
  <p class="lead" v-if="msg">[[ msg ]]</p>
</div>
{% endblock %}
{% block scripts %}
<script>
const { createApp } = Vue;
createApp({
  delimiters:['[[',']]'],
  data(){ return { scenes:[], selected:0, deviceId:'', msg:'' }; },
  computed:{
    previewSvg(){
      const s=this.scenes[this.selected]; if(!s||!s.frames||!s.frames[0]) return '';
      const el=s.frames[0].elements||{}; let out='';
      const draw=(arr,color)=>{ for(const p of (arr||[])){
        if(p.shape&&p.shape.indexOf('ellipse')===0) out+=`<ellipse cx="${p.x}" cy="${p.y}" rx="${p.rw}" ry="${p.rh}" fill="${color}"/>`;
        else if(p.shape==='line') out+=`<line x1="${p.x1}" y1="${p.y1}" x2="${p.x2}" y2="${p.y2}" stroke="${color}" stroke-width="2"/>`;
        else if(p.shape&&p.shape.indexOf('round_rect')===0) out+=`<rect x="${p.x}" y="${p.y}" width="${p.w}" height="${p.h}" rx="${p.radius||1}" fill="none" stroke="${color}" stroke-width="2"/>`;
      }};
      draw(el.eye_l,'#7fe7ff'); draw(el.eye_r,'#7fe7ff'); draw(el.mouth,'#ff9ec4'); draw(el.extra,'#ffd36b');
      return out;
    }
  },
  methods:{
    async load(){
      const d = await (await fetch('/app/api/devices')).json();
      this.deviceId = d.current_device_id || '';
      if(!this.deviceId){ this.msg='请先在「我的设备」选择一台设备'; return; }
      const r = await (await fetch('/api/face_expr_scenes?device_id='+encodeURIComponent(this.deviceId))).json();
      this.scenes = r.config || [];   // 场景在 config 键下（已实测）
    },
    async save(){
      if(!this.deviceId){ this.msg='没有当前设备，无法保存'; return; }
      const r = await (await fetch('/api/face_expr_scenes', {method:'POST',
        headers:{'Content-Type':'application/json'},
        body: JSON.stringify({device_id:this.deviceId, scenes:this.scenes})})).json();
      this.msg = r.ok ? '表情已保存到这台设备' : ('保存失败：'+(r.error||''));
    },
  },
  mounted(){ this.load(); },
}).mount('#app');
</script>
{% endblock %}
```

> 预览 `viewBox="0 0 120 80"` 与场景图元坐标范围匹配（图元 x≈0–90、y≈0–55）。接口形状已实测，无需再猜。

- [ ] **Step 2: 手动验收**

先在 `/my/devices` 绑定/选中一台设备，再访问 `/expr`：左侧大屏显示选中场景的首帧；点击不同「场景」缩略图，预览实时切换；点「保存表情」提示已保存。用 `GET /api/face_expr_scenes?device_id=…` 复核已写回。

- [ ] **Step 3: Commit**

```bash
git add src/deskbot_server/web/templates/app2c/expr.html
git commit -m "feat(web2c): expression page (scene picker + client preview + save)"
```

---

### Task 7: 它记得的事（调 /app/api/memories）

**Files:**
- Modify: `src/deskbot_server/web/templates/app2c/memories.html`

接口（已存在，用 session 当前设备）：`GET /app/api/memories`、`POST /app/api/memories` `{text}`、`DELETE /app/api/memories/<id>`。

- [ ] **Step 1: 写页面 + Vue（列表/新增/删除）**

```html
{% extends "base_2c.html" %}
{% block page_title %}它记得的事 · 小歪{% endblock %}
{% block extra_head %}<script src="{{ url_for('static', filename='vendor/vue.global.prod.min.js') }}"></script>{% endblock %}
{% block content %}
<div class="pagehd"><div><h1>它记得的事</h1><p>机器人记住的关于你的小事，随时可改可删。</p></div></div>
<div id="app">
  <div style="display:flex;gap:8px;margin-bottom:14px;max-width:560px">
    <input v-model="draft" placeholder="加一条它该记住的事…" style="flex:1;padding:10px 12px;border:1px solid var(--line);border-radius:12px">
    <button class="btn primary" @click="add">添加</button>
  </div>
  <div class="colwrap">
    <div class="note" v-for="m in items" :key="m.id">
      <p>[[ m.text ]]</p>
      <small>[[ m.created_at_fmt || '' ]]</small>
      <button class="btn ghost" style="margin-top:8px" @click="del(m)">删除</button>
    </div>
  </div>
  <p class="lead" v-if="msg">[[ msg ]]</p>
</div>
{% endblock %}
{% block scripts %}
<script>
const { createApp } = Vue;
createApp({
  delimiters:['[[',']]'],
  data(){ return { items:[], draft:'', msg:'' }; },
  methods:{
    async load(){ const r=await (await fetch('/app/api/memories')).json();
      if(r.ok) this.items=r.memories||[]; else this.msg=r.error||'加载失败'; },
    async add(){ const t=this.draft.trim(); if(!t) return;
      const r=await (await fetch('/app/api/memories',{method:'POST',headers:{'Content-Type':'application/json'},body:JSON.stringify({text:t})})).json();
      if(r.ok){ this.draft=''; this.load(); } else this.msg=r.error||'添加失败'; },
    async del(m){ const r=await (await fetch('/app/api/memories/'+m.id,{method:'DELETE'})).json();
      if(r.ok) this.load(); else this.msg=r.error||'删除失败'; },
  },
  mounted(){ this.load(); },
}).mount('#app');
</script>
{% endblock %}
```

- [ ] **Step 2: 手动验收**：`/my/memories` 能列出、添加、删除记忆（需已选当前设备）。

- [ ] **Step 3: Commit**

```bash
git add src/deskbot_server/web/templates/app2c/memories.html
git commit -m "feat(web2c): memories page via existing /app/api/memories"
```

---

### Task 8: 提醒 / 认识的人 / 我的设备（只读 + 删除/绑定）

**Files:**
- Modify: `src/deskbot_server/web/templates/app2c/reminders.html`
- Modify: `src/deskbot_server/web/templates/app2c/people.html`
- Modify: `src/deskbot_server/web/templates/app2c/devices.html`

接口（已存在）：`GET /app/api/scheduled-tasks` + `DELETE /app/api/scheduled-tasks/<id>`；`GET /app/api/face-profiles` + `DELETE /app/api/face-profiles/<person_id>`；`GET /app/api/devices` + `POST /app/api/devices` `{device_id,display_name}` + `POST /app/api/devices/select` `{device_id}`。

- [ ] **Step 1: reminders.html**

```html
{% extends "base_2c.html" %}
{% block page_title %}提醒 · 小歪{% endblock %}
{% block extra_head %}<script src="{{ url_for('static', filename='vendor/vue.global.prod.min.js') }}"></script>{% endblock %}
{% block content %}
<div class="pagehd"><div><h1>提醒</h1><p>它会在这些时间主动叫你。</p></div></div>
<div id="app">
  <div class="tl" v-for="t in tasks" :key="t.id">
    
    <div class="body"><b>[[ t.description || t.title || '提醒' ]]</b>
      <small>[[ (t.cron_expr || t.cron || '') + ' · 下次 ' + (t.next_run_at || '') ]]</small>
      <button class="btn ghost" style="margin-top:8px" @click="del(t)">删除</button>
    </div>
  </div>
  <p class="lead" v-if="!tasks.length">还没有提醒。</p>
</div>
{% endblock %}
{% block scripts %}
<script>
const { createApp } = Vue;
createApp({ delimiters:['[[',']]'], data(){return{tasks:[]};},
  methods:{ async load(){ const r=await (await fetch('/app/api/scheduled-tasks')).json(); if(r.ok) this.tasks=r.tasks||[]; },
    async del(t){ const r=await (await fetch('/app/api/scheduled-tasks/'+t.id,{method:'DELETE'})).json(); if(r.ok) this.load(); } },
  mounted(){ this.load(); } }).mount('#app');
</script>
{% endblock %}
```

> 任务对象由 `_task_to_dict()` 生成，含 `id/description/cron_expr/next_run_at/enabled` 等；模板已用 `||` 回退兼容 `cron`。

- [ ] **Step 2: people.html**

```html
{% extends "base_2c.html" %}
{% block page_title %}认识的人 · 小歪{% endblock %}
{% block extra_head %}<script src="{{ url_for('static', filename='vendor/vue.global.prod.min.js') }}"></script>{% endblock %}
{% block content %}
<div class="pagehd"><div><h1>认识的人</h1><p>机器人通过摄像头认识的人。</p></div></div>
<div id="app">
  <div class="people">
    <div class="person" v-for="p in profiles" :key="p.person_id">
      <div class="pa" style="background:linear-gradient(135deg,#6c5ce7,#a18bff)">[[ (p.name||'?').slice(0,1) ]]</div>
      <b>[[ p.name || ('#'+p.person_id) ]]</b>
      <button class="btn ghost" style="margin-top:6px" @click="del(p)">删除</button>
    </div>
  </div>
  <p class="lead" v-if="!profiles.length">还没有认识的人。</p>
</div>
{% endblock %}
{% block scripts %}
<script>
const { createApp } = Vue;
createApp({ delimiters:['[[',']]'], data(){return{profiles:[]};},
  methods:{ async load(){ const r=await (await fetch('/app/api/face-profiles')).json(); if(r.ok) this.profiles=r.profiles||[]; },
    async del(p){ const r=await (await fetch('/app/api/face-profiles/'+p.person_id,{method:'DELETE'})).json(); if(r.ok) this.load(); } },
  mounted(){ this.load(); } }).mount('#app');
</script>
{% endblock %}
```

> `person_id` / `name` 字段名以 `GET /app/api/face-profiles` 实际返回为准。

- [ ] **Step 3: devices.html**

```html
{% extends "base_2c.html" %}
{% block page_title %}我的设备 · 小歪{% endblock %}
{% block extra_head %}<script src="{{ url_for('static', filename='vendor/vue.global.prod.min.js') }}"></script>{% endblock %}
{% block content %}
<div class="pagehd"><div><h1>我的设备</h1><p>绑定与切换你的 Brufik 机器人。</p></div></div>
<div id="app">
  <div class="dev" v-for="d in devices" :key="d.device_id">
    <div class="di">🤖</div>
    <div style="flex:1"><b>[[ d.display_name ]]</b><br><small>[[ d.device_id ]]</small></div>
    <button class="btn" :class="d.device_id===current?'primary':'ghost'" @click="select(d)">[[ d.device_id===current?'当前':'切换' ]]</button>
  </div>
  <div style="display:flex;gap:8px;margin-top:14px;max-width:560px">
    <input v-model="newId" placeholder="设备 ID" style="flex:1;padding:10px 12px;border:1px solid var(--line);border-radius:12px">
    <button class="btn primary" @click="bind">绑定</button>
  </div>
  <p class="lead" v-if="msg">[[ msg ]]</p>
</div>
{% endblock %}
{% block scripts %}
<script>
const { createApp } = Vue;
createApp({ delimiters:['[[',']]'], data(){return{devices:[],current:'',newId:'',msg:''};},
  methods:{
    async load(){ const r=await (await fetch('/app/api/devices')).json(); if(r.ok){ this.devices=r.devices||[]; this.current=r.current_device_id||''; } },
    async select(d){ const r=await (await fetch('/app/api/devices/select',{method:'POST',headers:{'Content-Type':'application/json'},body:JSON.stringify({device_id:d.device_id})})).json(); if(r.ok){ this.current=r.current_device_id; } },
    async bind(){ const id=this.newId.trim(); if(!id) return; const r=await (await fetch('/app/api/devices',{method:'POST',headers:{'Content-Type':'application/json'},body:JSON.stringify({device_id:id})})).json(); if(r.ok){ this.newId=''; this.load(); } else this.msg=r.error||'绑定失败'; } },
  mounted(){ this.load(); } }).mount('#app');
</script>
{% endblock %}
```

> 设备图标 `🤖` 是内容占位，可换成 Lucide `device` 宏（`{{ icon('device') }}` 需在 macro 作用域内；如不便，保留中性图形）。

- [ ] **Step 4: 手动验收**：三页分别能列出提醒/人/设备，删除/绑定/切换生效。

- [ ] **Step 5: Commit**

```bash
git add src/deskbot_server/web/templates/app2c/reminders.html \
        src/deskbot_server/web/templates/app2c/people.html \
        src/deskbot_server/web/templates/app2c/devices.html
git commit -m "feat(web2c): reminders/people/devices pages via existing /app/api/*"
```

---

### Task 9: 高级 hub

**Files:**
- Modify: `src/deskbot_server/web/templates/app2c/advanced.html`

- [ ] **Step 1: 写 hub（链接既有页面，不迁移路由）**

```html
{% extends "base_2c.html" %}
{% block page_title %}高级 · 小歪{% endblock %}
{% block content %}
<div class="pagehd"><div><h1>高级</h1><p>开发者与进阶设置，普通使用一般用不到。</p></div></div>
<a class="adv-item" href="/app/usage"><div class="l">用量与账单</div><span>›</span></a>
<a class="adv-item" href="/app/llm-models"><div class="l">LLM 模型</div><span>›</span></a>
<a class="adv-item" href="/app/settings"><div class="l">账号 / API Key</div><span>›</span></a>
<a class="adv-item" href="/debug/devices"><div class="l">调试 · 设备</div><span>›</span></a>
<a class="adv-item" href="/debug/tts"><div class="l">调试 · TTS</div><span>›</span></a>
<a class="adv-item" href="/debug/llm"><div class="l">调试 · LLM</div><span>›</span></a>
<a class="adv-item" href="/debug/simulation"><div class="l">调试 · 模拟</div><span>›</span></a>
<p class="lead" style="margin-top:16px">＊ 这些都是既有控制台页面，功能不变，只是默认收起。</p>
{% endblock %}
```

在 `theme_2c.css` 末尾补 `a.adv-item{text-decoration:none}`（原型 `.adv-item` 是 div）。

- [ ] **Step 2: 手动验收**：`/advanced` 列出链接，点击进入既有页面且功能正常。

- [ ] **Step 3: Commit**

```bash
git add src/deskbot_server/web/templates/app2c/advanced.html src/deskbot_server/web/static/theme_2c.css
git commit -m "feat(web2c): advanced hub linking existing admin/debug pages"
```

---

### Task 10: 回归 — 既有页面与测试不受影响

- [ ] **Step 1: 跑全量测试**

Run: `cd service/deskbot-server && python -m pytest -q`
Expected: 全部 PASS（既有用例 + 新增 `test_app2c_pages.py`）

- [ ] **Step 2: 手动回归**：旧入口 `/app`、`/debug/*` 仍可访问、行为不变。

- [ ] **Step 3: Commit（如有微调）**

```bash
git add -A && git commit -m "test(web2c): full suite green after 2C shell"
```

---

## Phase 2 — 情绪→场景映射（可选）

> 仅当确认需要"给情绪指定表情场景"的持久化时实施。这是本计划唯一的新增后端。

### Task 11: emotion_expr_map_store（TDD）

**Files:**
- Create: `src/deskbot_server/emotion_expr_map_store.py`
- Create: `src/deskbot_server/constants.py` 中新增常量 `EMOTION_EXPR_MAP_FILE`（若 `constants.py` 已集中管理文件名）
- Test: `tests/test_emotion_expr_map_store.py`

- [ ] **Step 1: 写失败测试**

```python
# tests/test_emotion_expr_map_store.py
from __future__ import annotations

import tempfile
from pathlib import Path

import pytest

@pytest.fixture()
def map_file(monkeypatch):
    with tempfile.TemporaryDirectory() as tmp:
        path = Path(tmp) / "emotion_expr_map.json"
        monkeypatch.setattr(
            "deskbot_server.emotion_expr_map_store.EMOTION_EXPR_MAP_FILE",
            str(path),
        )
        yield path

def test_load_defaults_empty(map_file):
    from deskbot_server.emotion_expr_map_store import load_emotion_expr_map

    assert load_emotion_expr_map(device_id=None) == {}

def test_save_then_load_roundtrip(map_file):
    from deskbot_server.emotion_expr_map_store import (
        load_emotion_expr_map,
        save_emotion_expr_map,
    )

    save_emotion_expr_map({"happy": "smile", "sad": "sad"}, device_id=None)
    assert load_emotion_expr_map(device_id=None) == {"happy": "smile", "sad": "sad"}

def test_save_rejects_non_string_values(map_file):
    from deskbot_server.emotion_expr_map_store import save_emotion_expr_map

    with pytest.raises(ValueError):
        save_emotion_expr_map({"happy": 123}, device_id=None)
```

- [ ] **Step 2: 运行确认失败**

Run: `cd service/deskbot-server && python -m pytest tests/test_emotion_expr_map_store.py -q`
Expected: FAIL（模块不存在）

- [ ] **Step 3: 实现 store**

```python
# src/deskbot_server/emotion_expr_map_store.py
from __future__ import annotations

import json
import os
from typing import Optional

from deskbot_server.device_data import resolve_json_path

EMOTION_EXPR_MAP_FILE = "emotion_expr_map.json"

def _normalize(raw: object) -> dict[str, str]:
    if not isinstance(raw, dict):
        raise ValueError("emotion map must be an object")
    out: dict[str, str] = {}
    for k, v in raw.items():
        if not isinstance(v, str):
            raise ValueError(f"scene for emotion {k!r} must be a string")
        out[str(k)] = v
    return out

def load_emotion_expr_map(*, device_id: Optional[str] = None) -> dict[str, str]:
    path = resolve_json_path(EMOTION_EXPR_MAP_FILE, device_id)
    if not os.path.isfile(path):
        return {}
    with open(path, encoding="utf-8") as f:
        return _normalize(json.load(f))

def save_emotion_expr_map(
    mapping: dict[str, str], *, device_id: Optional[str] = None
) -> dict[str, str]:
    norm = _normalize(mapping)
    path = resolve_json_path(EMOTION_EXPR_MAP_FILE, device_id)
    os.makedirs(os.path.dirname(path) or ".", exist_ok=True)
    with open(path, "w", encoding="utf-8") as f:
        json.dump(norm, f, ensure_ascii=False, indent=2)
        f.write("\n")
    return norm
```

- [ ] **Step 4: 运行确认通过**

Run: `cd service/deskbot-server && python -m pytest tests/test_emotion_expr_map_store.py -q`
Expected: PASS（3 用例）

- [ ] **Step 5: Commit**

```bash
git add src/deskbot_server/emotion_expr_map_store.py tests/test_emotion_expr_map_store.py
git commit -m "feat(expr-map): per-device emotion->scene map store with tests"
```

---

### Task 12: 映射接口 GET/POST /api/emotion_expr_map（TDD）

**Files:**
- Modify: `src/deskbot_server/web/blueprints/app2c_bp.py`
- Test: `tests/test_emotion_expr_map_api.py`

- [ ] **Step 1: 写失败测试**

```python
# tests/test_emotion_expr_map_api.py
from __future__ import annotations

import tempfile
from pathlib import Path

import pytest

@pytest.fixture()
def temp_db(monkeypatch):
    with tempfile.TemporaryDirectory() as tmp:
        monkeypatch.setenv("DESKBOT_DB_PATH", str(Path(tmp) / "t.db"))
        from deskbot_server.db import init_database
        from deskbot_server.db.engine import init_engine, reset_engine

        reset_engine()
        init_engine(Path(tmp) / "t.db")
        init_database()
        yield

def _client():
    from deskbot_server.auth.device_service import bind_device
    from deskbot_server.auth.service import create_user
    from deskbot_server.web.app import create_app

    user = create_user("map@example.com", "password1234")
    bind_device(user.id, "deskbot_map")
    app = create_app()
    c = app.test_client()
    c.post("/login", data={"email": "map@example.com", "password": "password1234"})
    c.post("/app/api/devices/select", json={"device_id": "deskbot_map"})
    return c

def test_get_empty_then_post_roundtrip(temp_db):
    c = _client()
    g = c.get("/api/emotion_expr_map").get_json()
    assert g["ok"] is True and g["map"] == {}

    p = c.post("/api/emotion_expr_map", json={"map": {"happy": "smile"}}).get_json()
    assert p["ok"] is True

    g2 = c.get("/api/emotion_expr_map").get_json()
    assert g2["map"] == {"happy": "smile"}
```

- [ ] **Step 2: 运行确认失败**

Run: `cd service/deskbot-server && python -m pytest tests/test_emotion_expr_map_api.py -q`
Expected: FAIL（路由不存在 → 404）

- [ ] **Step 3: 实现接口**（追加到 `app2c_bp.py`）

```python
from flask import jsonify, request
from flask_login import current_user

from deskbot_server.auth.device_service import user_owns_device
from deskbot_server.emotion_expr_map_store import (
    load_emotion_expr_map,
    save_emotion_expr_map,
)
from deskbot_server.web.session_device import get_current_device_id

def _owned_device_or_error():
    device_id = (request.args.get("device_id") or get_current_device_id() or "").strip()
    if not device_id:
        return None, (jsonify({"ok": False, "error": "请先选择设备"}), 400)
    if not user_owns_device(current_user.id, device_id):
        return None, (jsonify({"ok": False, "error": "设备不属于当前账号"}), 403)
    return device_id, None

@bp.get("/api/emotion_expr_map")
@login_required
def emotion_expr_map_get():
    device_id, err = _owned_device_or_error()
    if err:
        return err
    return jsonify({"ok": True, "device_id": device_id, "map": load_emotion_expr_map(device_id=device_id)})

@bp.post("/api/emotion_expr_map")
@login_required
def emotion_expr_map_post():
    device_id, err = _owned_device_or_error()
    if err:
        return err
    payload = request.get_json(silent=True) or {}
    mapping = payload.get("map")
    if not isinstance(mapping, dict):
        return jsonify({"ok": False, "error": "map 必须是对象"}), 400
    try:
        saved = save_emotion_expr_map(mapping, device_id=device_id)
    except ValueError as exc:
        return jsonify({"ok": False, "error": str(exc)}), 400
    return jsonify({"ok": True, "map": saved})
```

> 说明：`device_id` 来自 query 或 session 当前设备；POST 用 JSON body（无 query 时回退 session）。POST 路径下 `request.args.get('device_id')` 为空将回退 `get_current_device_id()`，测试已 `select` 当前设备。

- [ ] **Step 4: 运行确认通过**

Run: `cd service/deskbot-server && python -m pytest tests/test_emotion_expr_map_api.py -q`
Expected: PASS

- [ ] **Step 5: Commit**

```bash
git add src/deskbot_server/web/blueprints/app2c_bp.py tests/test_emotion_expr_map_api.py
git commit -m "feat(expr-map): GET/POST /api/emotion_expr_map endpoints with tests"
```

---

### Task 13: 表情页接入情绪映射

**Files:**
- Modify: `src/deskbot_server/web/templates/app2c/expr.html`

- [ ] **Step 1: 在表情页加情绪→场景下拉**

在 Task 6 的 `expr.html` 内容区追加一段「情绪 → 表情」映射区（参考原型 `#emoMap` 与 `.maprow`），并在 Vue 中：
- `data` 增加 `emotions:[['happy','开心'],['surprised','惊讶'],['thinking','思考'],['sleepy','困'],['idle','待机']]` 与 `map:{}`。
- `mounted`/`load()` 末尾 `this.map = (await (await fetch('/api/emotion_expr_map')).json()).map || {}`。
- 每行一个 `<select v-model="map[key]">`，选项为 `scenes` 的 `name`（显示 `title`）。
- `save()` 末尾追加：`await fetch('/api/emotion_expr_map',{method:'POST',headers:{'Content-Type':'application/json'},body:JSON.stringify({map:this.map})})`。

完整片段：

```html
<div class="blocktitle">情绪 → 表情</div>
<div class="maprow" v-for="[k,label] in emotions" :key="k">
  <div class="lab">[[ label ]]</div>
  <select v-model="map[k]">
    <option value="">（不指定）</option>
    <option v-for="s in scenes" :key="s.name" :value="s.name">[[ s.title || s.name ]]</option>
  </select>
</div>
```

```javascript
// data(): 追加
emotions:[['happy','开心'],['surprised','惊讶'],['thinking','思考'],['sleepy','困'],['idle','待机']],
map:{},
// load() 末尾追加
this.map = ((await (await fetch('/api/emotion_expr_map'+(this.deviceId?('?device_id='+encodeURIComponent(this.deviceId)):''))).json()).map) || {};
// save() 末尾追加（在原 face_expr_scenes 保存之后）
await fetch('/api/emotion_expr_map',{method:'POST',headers:{'Content-Type':'application/json'},
  body:JSON.stringify({device_id:this.deviceId, map:this.map})});
```

- [ ] **Step 2: 手动验收**：表情页可给情绪选场景、保存后刷新仍在；`GET /api/emotion_expr_map` 复核。

- [ ] **Step 3: 跑全量测试**

Run: `cd service/deskbot-server && python -m pytest -q`
Expected: 全绿

- [ ] **Step 4: Commit**

```bash
git add src/deskbot_server/web/templates/app2c/expr.html
git commit -m "feat(web2c): wire emotion->scene mapping into expression page"
```

---

## 落地后说明（运行）

启动（既有方式）：`cd service && ./start.sh`，或单独 web：`cd service/deskbot-server && python -m deskbot_server.web`。
登录 `http://<IP>:5050/login` 后自动落地 `/home`。开发者入口仍在 `/app`、`/debug/*`，并由 `/advanced` 聚合。

## 接口形状（均已实测确认）
- `GET /api/face_expr_scenes` → 场景在 `config` 键下；POST body `{device_id, scenes:[…]}` 兼容。
- `GET /app/api/scheduled-tasks` → `{ok, tasks:[{id, description, cron_expr, next_run_at, enabled, …}]}`。
- `GET /app/api/face-profiles` → `{ok, profiles:[{person_id, name, …}]}`。
- `GET /api/doubao_tts/speakers` / `config` / `synthesize`、`/app/api/memories|devices` 均已在上文任务按真实返回接线。

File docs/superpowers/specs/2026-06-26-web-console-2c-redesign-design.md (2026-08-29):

# Web 控制台 2C 化改造 · 设计文档

- 日期：2026-06-26
- 范围：`service/deskbot-server` 的 Web 控制台（Flask + Jinja + 内联 Vue）
- 性质：交互层（前端 + 薄接口）重构，**不改动核心管线、协议、固件、调度、识别能力**

## 1. 背景与目标

现有 Web 控制台（端口 5050）是面向开发者/管理员的形态：侧边栏平铺 8+ 个功能页（dashboard / devices / scheduled-tasks / face-profiles / memories / llm-models / usage / account），外加 6 个 debug 调试页。术语和信息密度都偏工程向。

目标：把它改造成一个**面向普通用户（2C）的配套 App**——机器人本体仍是 ESP32 实体设备，网页是它的消费级配套（不另做原生客户端）。要求：

1. 所有复杂配置默认隐藏。
2. 把 **表情定制** 和 **声音定制** 做成两个核心可玩功能（产品主角）。
3. 复用现有后端能力，不改核心功能逻辑。

## 2. 非目标（明确不做）

- 不改动 ASR / LLM / TTS 管线、pb 协议、设备固件、定时调度、人脸识别等核心逻辑。
- 不做 **语速 / 音调** 调节（豆包 TTS 当前仅 `speaker` + `sample_rate`，无 speed/pitch）。
- 不做 **声音克隆**（后端无克隆能力）。
- 不删除任何现有功能；用量/账单、API Key、LLM 模型、debug 页全部保留，仅降权隐藏。
- 不引入新的前端框架（继续 Flask + Jinja + 内联 Vue）。

## 3. 现有能力盘点（设计的事实依据）

### 已有完整 JSON 接口（纯前端即可重新包装）
- 设备：`GET/POST /app/api/devices`、`POST /app/api/devices/select`、`DELETE /app/api/devices/<id>`
- 记忆：`GET/POST /app/api/memories`、`GET/PUT/PATCH/DELETE /app/api/memories/<id>`
- 提醒（定时任务）：`GET /app/api/scheduled-tasks`、`DELETE /app/api/scheduled-tasks/<id>`
- 人脸：`GET /app/api/face-profiles`、`DELETE /app/api/face-profiles/<person_id>`
- 用量：`/app/usage`（页面级）

### 已有 Web JSON 接口（实测，可直接被前端复用 —— 修正：并非"缺接口"）
两个英雄功能的后端接口其实**已存在于 `debug_bp`**，无需新增：
- 声音：
  - `GET /api/doubao_tts/speakers` → 音色画廊（`{ok, speakers:[{label,id,scene,resource_id,...}]}`）。
  - `GET /api/doubao_tts/config` / `POST /api/doubao_tts/config` → 读/设当前音色（POST 经 `save_doubao_tts_env` 写 `DOUBAO_TTS_SPEAKER` 并刷新进程环境，**全局生效**）。
  - `POST /api/doubao_tts/synthesize` → 试听，返回 `wav_base64`（浏览器可直接播放）。
- 表情：
  - `GET /api/face_expr_scenes?device_id=` → 按设备读场景（`load_face_expr_scenes_file`，缺省自动 seed `builtin_emotion_scenes()`）。
  - `POST /api/face_expr_scenes` → 按设备写场景（`save_face_expr_scenes_file`）。
- 场景数据形状：`{name:[a-z0-9_], title, frames:[{ms, elements:{mouth,nose,eye_l,eye_r,extra}}]}`。
- 音量：已支持（LLM JSON `volume` 字段 + 设备播放音量）。

> 影响：原计划的"4 个新薄接口"**作废**。改造主体变为**纯前端**（消费级外壳 + 页面，调用上述既有接口）。
> 唯一可能新增的后端 = 一个极小的 **per-device 情绪→场景映射 store**（见 §7.2 / §5.1，列为可选 Phase 2）。

## 4. 信息架构（三层）

> 形态：**桌面 Web App**（非移动端）。采用左侧固定导航栏 + 右侧内容区的经典 Web 布局；
> 一级导航项 = 家 / 表情 / 声音 / 它记得的事 / 提醒 / 认识的人 / 我的设备，底部一个降权的「⚙️ 高级」。

### ① 首页「家」（Home）
进入即见机器人：
- 大表情预览区（复用设备 284×240 画面渲染）。
- 状态条：在线/离线、当前音色名、当前性格/表情、"记得 N 件事 / N 个提醒"。
- 两张 C 位大卡片入口：🎭 捏表情 · 🔊 调声音。

### ② 中层功能
- 英雄功能（独立全屏体验）：🎭 表情、🔊 声音。
- 生活化功能（卡片入口，二级）：🧠 它记得的事、⏰ 提醒、👤 认识的人、📱 我的设备。

### ③ 底层「⚙️ 高级」
置于页脚或头像菜单，默认折叠、视觉降权。把现有管理页 **原样搬入** `/advanced/*`：用量/账单、API Key、LLM 模型、所有 debug 调试页。功能不删，普通用户不可见。

> 核心手法：不删功能，只**重新分层 + 重新命名 + 重新叙事**。
> face-profiles → 认识的人；memories → 它记得的事；scheduled-tasks → 提醒。

## 5. 英雄功能详细设计

### 5.1 🎭 表情定制
背靠 `face_expr_scenes_store`（per-device）。

- **皮肤打底**：顶部一排预设"面孔风格"缩略图（来自 `builtin_emotion_scenes()` / 现有场景），点击整套切换，右侧大图实时预览。
- **情绪挂表情**：情绪清单（开心 / 惊讶 / 思考 / 困 / 待机…），每个情绪一个下拉，映射到某个表情场景（即"情绪-表情映射"）。
- **所见即所得**：选中即在 284×240 大脸上播放该场景动画（纯前端用现有动画数据渲染）。
- **保存**：调薄接口写回 per-device 表情/映射数据。

### 5.2 🔊 声音定制
背靠 `doubao_tts_speakers.json` + `tts/speakers.py`。

- **音色画廊**：卡片网格列出豆包音色，按 `scene` 分组（客服 / 教育 / 有声阅读 / 视频配音…）。
- **试听**：每张卡 ▶️ 试听，走现有 TTS 合成路径念一句固定示例（不新增合成能力）。
- **设为当前音色**：写当前 speaker。
- **音量**：滑杆（后端已支持）。
- 不含语速/音调/克隆。

## 6. 生活化功能（纯前端，零后端改动）

| 现有 | 改名 | 交互 | 背靠接口 |
|---|---|---|---|
| memories | 🧠 它记得的事 | 便利贴式记忆卡，增/改/删 | `/app/api/memories`（已全有） |
| scheduled-tasks | ⏰ 提醒 | 时间轴列表，可删 | `/app/api/scheduled-tasks`（已有列/删） |
| face-profiles | 👤 认识的人 | 头像网格 + 名字，改名/删 | `/app/api/face-profiles`（已有列/删） |
| devices | 📱 我的设备 | 设备卡 + 在线灯 + 绑定向导 | `/app/api/devices`（已全有） |

dashboard 保留但瘦身，并入首页"家"页的状态条。

## 7. 技术落地

### 7.1 前端
- 继续 Flask + Jinja + 内联 Vue + `theme.css`，不引新框架。
- 新增消费级布局母版 `base_2c.html` 与新主题 `theme_2c.css`。
- 现有 `base.html` + 全部管理/调试页**原封不动**搬到 `/advanced/*` 作为"高级"区。
- 图标统一用 **Lucide**（ISC ≈ MIT 许可，24px 栅格 / 2px 圆角描边）；不使用 emoji 作为导航或卡片标签。可经包管理器引入或内联 SVG，保持全站一套图标语言。

### 7.2 后端改动（修正后：Phase 1 零新增，Phase 2 仅一个极小 store）

**Phase 1 — 零新增后端**：声音/表情/记忆/提醒/人/设备全部调用既有 JSON 接口（见 §3）。
唯一后端层面的改动是把**登录后落地页**指向新的消费首页（一处 redirect）。

**Phase 2（可选）— 情绪→场景映射**：现有 `face_expr_scenes_store` 存的是"场景列表"，不含"情绪→场景"映射。
若要实现 §5.1 的情绪映射持久化，新增一个极小 per-device store：

| 新增 | 作用 | 复用机制 |
|---|---|---|
| `emotion_expr_map_store.py` | 读/写 per-device `emotion_expr_map.json`（`{emotion_key: scene_name}`） | `device_data.resolve_json_path`（与 `face_expr_scenes_store` 同一 per-device 机制） |
| `GET/POST /api/emotion_expr_map` | 前端读写映射 | 上述 store |

- 试听复用既有 `POST /api/doubao_tts/synthesize`，不新增能力。
- 新增接口沿用现有 `before_request` 鉴权与 per-device 约定。

### 7.3 明确不动
ASR / LLM / TTS 管线、pb 协议、设备固件、定时调度、人脸识别。

## 8. 验收标准

1. 普通用户登录后首屏即见机器人 + 表情/声音两个入口，看不到任何 debug/API Key/模型/用量术语。
2. 表情：能切换皮肤、给至少 4 种情绪指定表情场景、实时预览、保存后通过 `GET /app/api/expressions` 可读回。
3. 声音：能浏览按场景分组的音色画廊、试听、设为当前音色（`POST /app/api/voice/active` 生效）、调音量。
4. 记忆/提醒/认识的人/设备四项均以新叙事呈现，且 CRUD 行为与原接口一致。
5. `/advanced/*` 下原有全部管理/调试功能可访问、行为不变。
6. 核心管线/协议/固件无任何代码改动。

## 9. 风险与依赖

- 表情实时预览需在浏览器用现有动画数据渲染 284×240 画面；若现有 pb/动画数据格式不便于前端直接渲染，预览可降级为"静态首帧 + 场景名"，不阻塞保存能力。
- 试听依赖 TTS 服务在线；离线时按钮置灰并提示。
- 设当前音色的写入位置（env vs config.yaml）需在实现期确认生效路径，确保与设备实际取用一致。

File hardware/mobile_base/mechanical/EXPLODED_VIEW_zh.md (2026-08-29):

# Brufik + N3 爆炸展示图分组

爆炸图以整机装配轴为中心，结构关系优先于零件数量。外壳向左右拆开，电子件沿竖直方向分层，三组轮电机沿各自径向拆开。

## A. 头部与 Y 轴俯仰机构

1. 显示器前框
2. 40 × 33 mm 显示器模块与固定柱
3. 头部内部载板/线束夹
4. 头部后壳
5. Y 轴 9 g 舵机
6. 舵盘、输出轴和紧固件
7. 右侧舵机检修盖
8. 左侧从动轴承盖
9. U 形俯仰支架

头部前框和后壳沿前后方向分离；左右轴盖沿俯仰轴方向分离；9 g 舵机必须落在右后侧支架内，不能悬浮在头壳外。

## B. X 轴回转与原机器人机身

10. 中空线束立柱
11. 上回转环/轴承面
12. X 轴 2 g 舵机
13. 小齿轮、回转大齿轮及压板
14. ESP32 C3 Sense 核心板（按约 21 × 18 mm XIAO 类包络预留）
15. OV2640 摄像头模块（暂按最大 24 × 24 mm 包络）
16. 可更换摄像头转接托架与镜头压圈
17. 麦克风与扬声器组件
18. 带摄像头窗口的机身前检修盖
19. 圆角胶囊式机身后罩
20. 扬声器侧盖/声孔导管
21. 下回转座

机身左右壳沿横向分离，PCB、摄像头和声学器件留在内部骨架上；拆壳不改变 X 轴齿轮啮合和舵机中位。

## C. 移动底盘电子舱

22. 上半身转接座
23. 低矮电子舱上罩
24. 后部电源/充电检修盖
25. 92 × 74 mm 移动控制 PCB
26. 2S 电池及可更换电池托盘
27. 58 × 49 mm 安装孔转接板
28. 防振垫与 M3 紧固件

控制板与电池以水平层叠方式展示，不在图中虚构并排空间；插头方向和电池尺寸最终确认后再锁定托盘。

## D. N3 三轮底盘

29. 3 mm 上层亚克力板
30. 六根 30 mm M3 铜柱
31. 三组 N20 电机与固定座
32. 三只 50 mm 全向轮
33. 3 mm 下层亚克力板

上、下亚克力板沿竖直方向分离；每组 N20 电机、固定座和全向轮沿其径向向外分离，保持三组相隔 120° 的关系。

## 展示规则

- 采用前左上方等轴测视角，整机中心轴保持垂直。
- 相邻层爆炸距离为 18–30 mm；外壳左右分离 35–45 mm；轮组径向分离 30–40 mm。
- 外壳为暖白色，运动/承力件为深石墨色，PCB 为绿色，电池为深灰色，紧固件为金属色。
- 第一张展示图不放文字标签，避免生成图中文字失真；后续在确定 CAD 后叠加矢量编号和 BOM 图例。
- 所有零件都必须沿合理装配方向移动，不使用互相穿插或无法装入的“装饰性爆炸”。
- 摄像头窗口属于主外壳，OV2640 只固定在内部通用托架上；若更换其他摄像头，仅替换托架/内衬，不修改机身主壳。核心板与摄像头必须始终作为两个独立零件展示。

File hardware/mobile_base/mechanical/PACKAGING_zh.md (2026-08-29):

# Brufik + N3 外壳内部包络基准

这份文件用于约束外形设计。任何外壳造型都必须先满足以下硬件包络、运动间隙和检修要求。

## 1. 已确认的固定尺寸

| 部件 | 固定/工程包络 | 位置与约束 |
| --- | --- | --- |
| N3 三轮底盘 | 160 × 150 × 65 mm | 保留原两层 3 mm 亚克力板、三只 50 mm 全向轮及 N20 电机，不改变轮组位置。 |
| 原 Brufik 上半身总成 | 约 60 × 57 × 106 mm | 来自作者整机 STEP 的总体包络；作为完整功能模块安装在 N3 顶板中心，不重新布置原机构。 |
| 显示器有效模块 | 约 40 × 33 mm，厚度约 3–4 mm | 头部外壳外尺寸控制在约 58–60 × 40–43 × 50–54 mm。 |
| Y 轴 9 g 舵机 | 约 28.5 × 12 × 32.3 mm | 位于显示器后方，负责俯仰；必须保留舵盘、连杆和线束随动空间。 |
| X 轴 2 g 舵机 | 暂按 20 × 12 × 22 mm 工程包络 | 位于上半身底座内，通过齿轮/立柱负责水平转动；位置沿用作者结构。 |
| 原机器人主 PCB | 板框约 35.3 × 45.2 mm | 留 12 mm 元件与插头高度，继续放在原上半身底座内。 |
| ESP32 C3 Sense 核心板 | 暂按约 21 × 18 mm XIAO 类包络 | 与摄像头分开固定，USB-C、天线和排针方向最终按实物锁定。 |
| OV2640/替代摄像头 | 通用托架暂按最大 24 × 24 mm | 镜头中心对准前盖窗口；通过可更换转接托架兼容其他系列，不改主外壳。 |
| 移动底盘 PCB | 92 × 74 mm | 放在 N3 顶板上方、外罩内部；按 20 mm 总高预留，包含 DRV8833、降压、电解电容和接插件。 |
| N3 安装孔 | 58 × 49 mm | 用于移动 PCB/转接架定位，不把外壳直接锁在薄壁上。 |

## 2. 暂定件（拿到实物尺寸后收紧）

| 部件 | 当前预留包络 | 处理方式 |
| --- | --- | --- |
| 2S 电池 | 74 × 40 × 22 mm | 横向平放在移动 PCB 后侧或下层；电池仓允许更换内衬，不把尺寸写死在主外壳上。 |
| 电源开关/充电口 | 30 × 18 × 15 mm 服务区 | 放在后部独立小盖板，USB/充电线不穿过舵机运动区。 |

## 3. 运动与打印间隙

- N3 底板采用原始圆角六边形/三角形平面轮廓；三组 N20 电机与 50 mm 全向轮围绕底盘几何中心等角布置，相邻轮组夹角固定为 120°，前方一组、后方左右各一组，禁止改成矩形四角布局。
- 头部俯仰按至少 -20° 到 +20° 设计，头壳后缘与 9 g 舵机罩之间保留 3 mm 动态间隙。
- 水平转动按至少左右各 30° 设计；中心立柱、齿轮和线束通道组成独立转台，不让外罩承受舵机力。
- 普通固定装配面单侧留 1.2–1.5 mm FDM 间隙；运动件单侧留 2.5–3 mm。
- 轮子最高点及摆动轮廓之外保留至少 4 mm；外罩不遮挡轮缘，也不能成为第四个落地点。
- 线束穿过旋转轴时留直径至少 12 mm 的中空通道，并预留松弛环，避免反复扭线。

## 4. 推荐空间分层

1. **0–65 mm：N3 原底盘层**——N20 电机、全向轮、原亚克力板和立柱保持不变。
2. **65–93 mm：动力电子层**——92 × 74 mm 移动 PCB 与 2S 电池置于低矮圆角外罩中；外罩高度从旧版约 18 mm 增加到约 28 mm。
3. **93–135 mm：原机器人底座层**——保留原 PCB、X 轴 2 g 舵机、减速齿轮和回转立柱；外形应是明确的阶梯式基座，而不是无法容纳机构的细脖子。
4. **135–190 mm：Y 轴和头部层**——9 g 舵机在屏幕后形成真实后脑体积，头壳围绕显示器和舵机包络成型。

预计整机高度约 185–195 mm，具体由转接座厚度和电池最终尺寸决定。

## 5. 外壳拆分与检修

- 底盘罩：前罩 + 后部检修盖，拆盖即可接触移动 PCB、电池、总电源和 USB。
- 上半身罩：左右两片或前后两片，拆壳不需要卸下舵机输出臂。
- 上半身外壳当前造型基准为约 70–74 × 62–66 × 52–58 mm 的圆角胶囊舱；前盖包含约 18 × 13 mm 摄像头窗口和麦克风孔，后罩包覆主 PCB、2 g 舵机与齿轮，侧面设置扬声器槽。顶部回转环为独立运动件，与固定外壳保持约 3 mm 周向间隙。
- 头壳：前框、后盖、独立 Y 轴舵机侧盖；先松侧盖即可校准舵盘中位。
- 外壳只负责防护和外观；所有电机、PCB 和电池都固定在内部骨架/转接板上。

## 6. 下一步必须实测

- 2S 电池长、宽、厚和插头出线方向。
- 实际 2 g 舵机壳体、安装耳和输出轴尺寸。
- 92 × 74 mm 移动 PCB 上最高器件高度，以及电源/电机插头朝向。
- N3 三个轮子的中心位置和顶板可用螺孔坐标。

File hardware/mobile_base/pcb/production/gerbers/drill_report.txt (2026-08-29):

Drill report for BrufikMobileBase.kicad_pcb
Created on 2026-08-06T22:40:01

Copper Layer Stackup:
    =============================================================
    L1 :  F.Cu                      front
    L2 :  In1.Cu                    in1
    L3 :  In2.Cu                    in2
    L4 :  B.Cu                      back

Drill file 'BrufikMobileBase-PTH.drl' contains
    plated through holes:
    =============================================================
    T1  0.300mm  0.0118"  (52 holes))
    T2  0.450mm  0.0177"  (1 hole)
    T3  1.000mm  0.0394"  (33 holes))
    T4  1.200mm  0.0472"  (2 holes))

    Total plated holes count 88

Drill file 'BrufikMobileBase-NPTH.drl' contains
    unplated through holes:
    =============================================================
    T1  3.600mm  0.1417"  (4 holes))

    Total unplated holes count 4

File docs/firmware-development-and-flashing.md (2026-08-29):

# 包逗固件修改、编译与烧录指南

这份文档同时面向维护者和后续 Coding Agent。目标是让接手者在不泄露本地密钥、不误伤舵机机械结构的前提下，快速理解当前烧录版本、修改固件、完成编译烧录并判断机器人是否正常启动。

## 1. 当前机器人运行的是什么

当前实机使用 **ESP32 直连豆包 Realtime** 的固件路径：

```text
PDM 麦克风
  -> ESP32 PCM16 16 kHz 上行
  -> 豆包 Realtime（ASR + 对话模型 + 流式 TTS）
  -> ESP32 PCM16 24 kHz 流式播放
  -> MAX98357 + 喇叭
```

它不依赖自建语音服务器完成日常对话。设备启动后会直接建立：

```text
wss://openspeech.bytedance.com/api/v3/duplex/realtime/dialogue
```

当前能力包括：

- 全双工连续对话和语音打断；
- 豆包 Realtime 直接返回流式语音；
- 大模型通过工具控制头部、表情、音量和收音灵敏度；
- 用户询问镜头前物体时，Realtime 调用 `inspect_camera`，设备拍摄 OV2640 画面并交给 Seed VLM；
- 播放 PCM 音频时按实际音量驱动嘴型；
- 空闲时保留眨眼、左右看、困倦、打哈欠、睡觉和打鼾等端侧微表情。

当前默认角色是“豆包的妹妹包逗”，固定自我介绍为：

> 我是豆包的妹妹包逗，可以天天逗你开心。

### 当前模型与音频参数

| 项目 | 当前值/来源 |
|---|---|
| Realtime 模型 | `DESKBOT_DOUBAO_MODEL`，当前默认 `1.2.6.1` |
| Realtime 音色 | `zh_female_xiaohe_jupiter_bigtts` |
| 视觉模型 | `doubao-seed-2-1-turbo-260628` |
| 麦克风上行 | PCM16 单声道，16 kHz，20 ms/帧，100 ms/次 WebSocket 写入 |
| 语音下行 | PCM16LE 单声道，24 kHz |
| 播放预缓冲 | 默认 600 ms，见 `DESKBOT_DIRECT_AUDIO_PREBUFFER_MS` |
| Realtime 会话 | `input_mod=keep_alive`，连续对话无需每轮重新叫名字 |

## 2. 后续 Coding Agent 先读这里

固件入口是 [`hardware/firmware/deskbot_rom.ino`](../hardware/firmware/deskbot_rom.ino)。建议按下列顺序了解代码：

1. [`hardware/firmware/deskbot_config.h`](../hardware/firmware/deskbot_config.h)：模式开关、模型、引脚、音频阈值和公共参数；
2. [`hardware/firmware/deskbot_rom.ino`](../hardware/firmware/deskbot_rom.ino)：完整启动顺序和任务创建顺序；
3. [`hardware/firmware/direct_realtime.cpp`](../hardware/firmware/direct_realtime.cpp)：当前主链路、模型提示词、工具调用、视觉、下行播放和空闲表情；
4. [`hardware/firmware/head.h`](../hardware/firmware/head.h) 与 [`head.cpp`](../hardware/firmware/head.cpp)：舵机范围、校准、镜像、相对/绝对运动、点头和摇头；
5. [`hardware/firmware/mic.cpp`](../hardware/firmware/mic.cpp)、[`speaker.cpp`](../hardware/firmware/speaker.cpp)：音频采集、回声抑制、音量和流式播放；
6. [`hardware/firmware/camera.cpp`](../hardware/firmware/camera.cpp)：OV2640 初始化及实时 JPEG 拍摄；
7. [`hardware/platformio.ini`](../hardware/platformio.ini)：开发板、分区、依赖和编译补丁。

### 常见需求对应的修改位置

| 想修改什么 | 首选文件 | 注意事项 |
|---|---|---|
| 名字、人设、自我介绍、工具调用策略 | `direct_realtime.cpp` 的 `send_session_create()` | 提示词会随每次 Realtime 会话创建发送 |
| Realtime 工具定义 | `direct_realtime.cpp` 的 `add_tool_schemas()` | 同时检查 `run_local_tool()` 和工具完成事件 |
| 视觉提问和回答风格 | `direct_realtime.cpp` 的 `call_seed_vlm()` | 视觉会暂时释放 Realtime TLS 内存，见下文 |
| 表情、空闲微表情、嘴型阈值 | `direct_realtime.cpp` 的 `kFace*`、`pump_idle_expression()`、`render_mouth_level()` | 表情是 PB 矢量 JSON，不是图片资源 |
| X/Y 中位、边界和速度 | `head.h`、`head.cpp` | 实机机械风险最高，必须小步测试 |
| LCD、舵机、I2S、PDM 引脚 | `deskbot_config.h` | 以此文件为唯一真值，不要只看旧接线图 |
| 麦克风增益和门控 | `mic.cpp`、`deskbot_config.h` | 默认增益 5，模型工具可切换 3/5/8 |
| 播放音量、队列和 I2S | `speaker.cpp`、`speaker.h` | 嘴型依赖实际写入 I2S 的 PCM 幅度 |
| 摄像头方向、亮度、画质 | `camera.cpp` | 当前 VGA、JPEG quality 10、垂直翻转 |
| 启动任务顺序 | `deskbot_rom.ino` | 摄像头必须先初始化，舵机再永久 attach |

### 当前视觉链路为什么会有等待

ESP32-S3 的内部 SRAM 无法稳定同时容纳 Realtime WSS 和 Ark HTTPS 两套 mbedTLS 缓冲。执行 `inspect_camera` 时当前逻辑会：

1. 先说“等一下，我仔细看看”；
2. 暂时断开 Realtime WSS，释放 TLS 内存；
3. 拍摄最新一帧 VGA JPEG；
4. 调用 Ark Responses API 的 Seed VLM；
5. 重连 Realtime，再播放视觉回答。

因此视觉调用比普通语音问答慢是当前架构特征。不要在不了解内部 SRAM 余量时同时保留两条 TLS 连接。

## 3. 当前硬件和舵机标定

主控为 **Seeed XIAO ESP32S3 Sense**，PlatformIO 环境名为 `seeed_xiao_esp32s3`，串口波特率为 `115200`。

| 外设 | 当前连接 |
|---|---|
| LCD ST7789 | MOSI D10/GPIO9，SCK D8/GPIO7，CS D1/GPIO2，DC D2/GPIO3 |
| 左右 X 舵机 | D9/GPIO8 |
| 上下 Y 舵机 | D3/GPIO4 |
| MAX98357 | DIN D0/GPIO1，BCLK D5/GPIO6，LRC D4/GPIO5 |
| PDM 麦克风 | CLK GPIO42，DATA GPIO41 |

当前代码中的舵机逻辑范围：

| 轴 | 最小 | 中位 | 最大 | 特殊逻辑 |
|---|---:|---:|---:|---|
| X 左右 | -20 | 40 | 100 | `X_OUTPUT_GAIN=2` 补偿约 2:1 齿轮；Realtime 工具下行还会做 X 镜像 |
| Y 上下 | -10 | 50 | 80 | 数值减小为抬头，增大为低头 |

X 轴在 `head.cpp` 中以“逻辑 30° = 1167 µs”作为实机校准点，再围绕它按 2 倍舵机输出增益换算脉宽。不要把模型工具坐标、逻辑角和最终舵机 PWM 角混为一谈。

修改舵机参数时：

- 先记录当前 `X/Y` 中位和边界；
- 每次只改一个轴，边界每次最多扩 5–10°；
- 先执行 `head_move_abs_ex` 慢速靠近边界；
- 听到持续堵转声立刻断电，并收紧对应边界；
- X 方向错误时先检查 Realtime 工具中的镜像，不要同时反转底层 PWM 和工具映射。

## 4. 首次准备本地配置

真实 Wi-Fi 和火山凭证不得写入受 Git 跟踪的文件。仓库根目录执行：

```powershell
Copy-Item .\hardware\firmware\deskbot_local_config.example.h `
  .\hardware\firmware\deskbot_local_config.h
Copy-Item .\service\.env.example .\service\.env
```

编辑被忽略的 `hardware/firmware/deskbot_local_config.h`：

- 填写 `WIFI_DEFAULT_SSID`、`WIFI_DEFAULT_PASSWORD`；
- 保持 `DESKBOT_DIRECT_CLOUD=1`；
- 自建服务模式才需要 `DESKBOT_WS_HOST` 和 `DESKBOT_API_KEY`。

编辑被忽略的 `service/.env`，直连固件至少需要：

```dotenv
DOUBAO_REALTIME_APP_ID=
DOUBAO_REALTIME_ACCESS_TOKEN=
ARK_API_KEY=
```

`hardware/scripts/build_direct.ps1` 会在编译期间把这三个值临时变成编译宏，不会改写受 Git 跟踪的源码，也不会主动打印凭证。火山 Secret Key 不参与当前设备端 Realtime 链路，不应编进固件。

## 5. Windows 环境准备

推荐使用 Python 3 + PlatformIO Core。先确认 Python：

```powershell
python --version
```

安装 PlatformIO：

```powershell
python -m pip install --upgrade platformio
python -m platformio --version
```

如果机器上有多个 Python，请固定使用装有 PlatformIO 的解释器：

```powershell
$pioPython = python -c "import sys; print(sys.executable)"
& $pioPython -m platformio --version
```

工程路径含中文时不要手工搬目录。`build_direct.ps1` 会临时把 `hardware` 映射到 ASCII 盘符 `H:`，编译结束后自动释放。

## 6. 找到机器人的串口

插入机器人 USB 后执行：

```powershell
Get-CimInstance Win32_SerialPort | Format-Table DeviceID, Name
python -m platformio device list
```

记住设备对应端口，例如 `COM4`。烧录前关闭 Arduino IDE、串口监视器或其他占用该端口的程序。

## 7. 编译和烧录当前直连版

以下命令均从仓库根目录运行。

### 只编译

```powershell
.\hardware\scripts\build_direct.ps1 -BuildOnly
```

如果 `python` 不是装有 PlatformIO 的解释器：

```powershell
.\hardware\scripts\build_direct.ps1 -BuildOnly -PythonPath $pioPython
```

### 编译并烧录

把 `COM4` 换成实际端口：

```powershell
.\hardware\scripts\build_direct.ps1 -UploadPort COM4
```

或指定 Python：

```powershell
.\hardware\scripts\build_direct.ps1 `
  -UploadPort COM4 `
  -PythonPath $pioPython
```

成功时 PlatformIO 最后应显示 `SUCCESS`。烧录会让设备自动复位。

### 打开串口日志

```powershell
python -m platformio device monitor `
  -d .\hardware `
  -e seeed_xiao_esp32s3 `
  -p COM4 `
  -b 115200
```

退出串口监视器使用 `Ctrl+C`。

> `hardware/flash_rom.sh` 主要服务 Linux/macOS 和旧的服务端模式。当前直连版需要从 `service/.env` 注入 Realtime/Ark 凭证，Windows 上优先使用 `build_direct.ps1`，不要直接用普通 `pio run` 误烧成缺少直连凭证的版本。

## 8. 烧录后的启动判断

正常启动日志大致依次出现：

```text
[BOOT] device_id=...
[CAMERA] setup_camera ok framesize=VGA quality=10
[DIRECT] setup ok ...
[DIRECT] connecting wss://openspeech.bytedance.com:443/...
[DIRECT] session ready; microphone open
[BOOT] ready ... mode=direct-cloud ... wifi_ip=...
```

建议完成以下冒烟测试：

1. 叫“包逗”，确认能回应“我在”；
2. 连续问两轮，不重复叫名字，确认能连续对话；
3. 让它抬头、低头、向左看、向右看；
4. 说一句明确肯定或否定的话，确认点头/摇头时仍有语音；
5. 让它切换开心或睡觉表情；
6. 让它调大/调小音量、调整远场收音；
7. 把物体放到镜头前问“这是什么”，确认先有等待提示，再返回视觉结果；
8. 让它说一段长句，确认声音连续、后半句音量正常、嘴型持续跟随。

### 串口直接测试舵机

串口监视器支持纯文本 factory 命令：

```text
head_pos
head_move_abs_ex 40 50 1 300
head_nod
head_shake
head_center
reboot
```

其中 `head_move_abs_ex <x> <y> <step> [hold_ms]` 适合慢速标定。命令仍会受代码中的硬限位约束，但硬限位不保证机械一定安全。

## 9. 常见问题

### 找不到 PlatformIO

确认安装到当前 Python：

```powershell
python -m pip show platformio
python -m platformio --version
```

若只有另一个 Python 安装了 PlatformIO，把那个解释器的绝对路径传给 `-PythonPath`。

### 找不到串口或上传失败

- 换一根支持数据的 USB 线；
- 关闭占用 COM 口的软件；
- 重新插拔并再次执行 `platformio device list`；
- 必要时按住 BOOT、短按 RESET、松开 BOOT，使 ESP32-S3 进入下载模式后重试。

### 启动后没有语音

优先检查日志是否出现：

- `missing Doubao APP ID or Access Token`：直连凭证没有注入；
- `WiFi connect failed`：Wi-Fi 配置或热点不可用；
- `session ready timeout` / `disconnected`：网络、代理或火山端连接异常；
- `downlink queue full`：音频下行消费不及时。

### 摄像头一直回答没看清

检查：

- 启动时是否有 `[CAMERA] setup_camera ok`；
- 调用时是否有 `[DIRECT VLM] scheduling`、`direct capture` 和 `completed`；
- `ARK_API_KEY` 是否有效；
- 是否出现 `TLS handoff timeout` 或 Ark HTTP 状态码错误。

### 舵机持续响或顶住外壳

立即断电。缩小 `head.h` 中对应轴的 `*_MIN_LIMIT` / `*_MAX_LIMIT`，不要通过增加脉宽范围解决。重新上电前先核对齿轮装配和中位。

## 10. Coding Agent 的安全修改流程

每次修改固件建议遵循：

```powershell
git status --short
python .\scripts\check_no_local_secrets.py
.\hardware\scripts\build_direct.ps1 -BuildOnly -PythonPath $pioPython
```

接上机器人后再执行：

```powershell
.\hardware\scripts\build_direct.ps1 -UploadPort COM4 -PythonPath $pioPython
```

最后检查：

```powershell
python .\scripts\check_no_local_secrets.py
git diff --check
git diff
```

对后续 Coding Agent 的约束：

- 不读取、打印、提交或在文档中复制真实 Wi-Fi、Access Token、API Key；
- 不使用 `git add -f` 添加 `deskbot_local_config.h` 或 `service/.env`；
- 修改舵机前先读完 `head.h` 和 `head.cpp` 的坐标变换；
- 不在一次修改里同时调整 X 镜像、X 增益、中位和边界；
- 不把旧服务端链路的 PB/ASR 逻辑误认为当前实机主链路；
- 修改 Realtime 事件名或会话结构时，以火山当前接口规范和实机日志共同验证；
- 只有编译成功不代表实机通过，音频、视觉和舵机改动必须分别做冒烟测试。

本地凭证与 GitHub 发布的完整说明另见 [`local-config-and-github.md`](local-config-and-github.md)。

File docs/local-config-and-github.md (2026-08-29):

# 包逗本地配置、刷写与 GitHub 发布

本文档的目标是：真实 Wi‑Fi、设备鉴权和火山凭证只保留在本机，GitHub 仓库只保存空默认值、示例和代码。

## 1. 配置文件分层

| 文件 | 是否提交 | 用途 |
|---|---:|---|
| `hardware/firmware/deskbot_local_config.example.h` | 是 | 固件本地配置模板 |
| `hardware/firmware/deskbot_local_config.h` | 否 | Wi‑Fi、服务地址、设备 API Key、直连模式开关 |
| `service/.env.example` | 是 | 火山与服务端环境变量模板 |
| `service/.env` | 否 | Ark、Realtime、TTS 等真实凭证 |

不要使用 `git add -f` 强制添加两个本地文件。

## 2. 首次本地配置

在仓库根目录运行 PowerShell：

```powershell
Copy-Item .\hardware\firmware\deskbot_local_config.example.h `
  .\hardware\firmware\deskbot_local_config.h
Copy-Item .\service\.env.example .\service\.env
```

编辑 `deskbot_local_config.h`：

- `WIFI_DEFAULT_SSID` / `WIFI_DEFAULT_PASSWORD`：机器人连接的网络；
- `DESKBOT_WS_HOST` / `DESKBOT_API_KEY`：仅自建服务模式需要；
- `DESKBOT_DIRECT_CLOUD=1`：ESP32 直接连接豆包实时模型。

编辑 `service/.env`，直连版至少填写：

- `ARK_API_KEY`：Seed VLM 摄像头识别；
- `DOUBAO_REALTIME_APP_ID`；
- `DOUBAO_REALTIME_ACCESS_TOKEN`。

Secret Key 不参与当前 Realtime WebSocket 协议，不应写入固件。

## 3. 编译与刷写直连版

安装 PlatformIO 后运行：

```powershell
.\hardware\scripts\build_direct.ps1 -UploadPort COM4
```

只编译、不刷写：

```powershell
.\hardware\scripts\build_direct.ps1 -BuildOnly
```

脚本从 `service/.env` 临时生成编译宏，不会把值写入受 Git 跟踪的文件，也不会主动打印凭证。工程路径含中文时，脚本会临时映射 ASCII 盘符，规避 ESP32 链接器路径问题。

如果 `pio` 不在 PATH，可指定安装了 PlatformIO 的 Python：

```powershell
.\hardware\scripts\build_direct.ps1 -UploadPort COM4 `
  -PythonPath C:\path\to\python.exe
```

## 4. 提交前安全检查

```powershell
git check-ignore -v hardware/firmware/deskbot_local_config.h service/.env
python .\scripts\check_no_local_secrets.py
git status --short
git diff --cached
```

前两个本地文件必须显示为 ignored；凭证扫描必须返回 `ok`。

注意：密钥虽然不进入 Git，但直连版必须把必要凭证编译进 ESP32 固件。量产时应使用最小权限凭证、设置配额，并准备远程轮换或设备级临时令牌方案。

## 5. 发布到自己的 GitHub

当前 `origin` 指向上游 `OpenDeskBot/brufik_in_one`。建议先在 GitHub 创建一个私有仓库，然后把上游保留为 `upstream`：

```powershell
git remote rename origin upstream
git remote add origin https://github.com/<你的用户名>/<仓库名>.git
git add -A
python .\scripts\check_no_local_secrets.py
git diff --cached
git commit -m "feat: add Baodou direct realtime robot"
git push -u origin feature/realtime-direct-esp32
```

旧上游历史曾使用过非空的示例网络或鉴权值。发布为公开仓库前，应先轮换所有历史凭证；若要求历史中完全不含任何旧值，应另外创建无历史的干净发布分支，而不是直接公开完整历史。

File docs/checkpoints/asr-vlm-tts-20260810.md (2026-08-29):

# 包逗 ASR + VLM + TTS 稳定基线

保存日期：2026-08-10

## 链路

1. ESP32 上传麦克风 Opus 音频。
2. 服务端完成本地唤醒、VAD 与 ASR。
3. 文本 LLM 负责对话和工具调度。
4. 视觉问题通过摄像头快照与 VLM 工具处理。
5. 独立 TTS 合成 24 kHz 音频并下发 ESP32。
6. 舵机、表情、音量、收音配置继续使用现有工具链。

`service/config.yaml` 中 `realtime.enabled` 在此基线固定为 `false`。Doubao Realtime 代码可以保留，但不会进入默认语音链路。

## 本地私有配置

凭证和设备网络配置不进入 Git。当前机器上的副本位于：

- `.codex-backups/asr-vlm-tts-20260810/private/service.env`
- `.codex-backups/asr-vlm-tts-20260810/private/deskbot_config.h`

恢复时将它们分别复制回 `service/.env` 和 `hardware/firmware/deskbot_config.h`。

## 回归结果

稳定链路相关测试共 69 项：

- 66 项通过。
- 2 项合成音频 VAD 用例在本机 Silero 模型下未产生句末事件。
- 1 项在 Windows 下因 SQLite 测试连接未及时释放，临时数据库清理失败。

真机已经完成 ASR 问答、摄像头识物、TTS 下行、舵机与表情控制验证。上述三个测试问题作为已知测试环境问题保留，不等同于真机链路失效。

## 启动

在 PowerShell 中运行：

```powershell
cd service
.\start_windows.ps1
```

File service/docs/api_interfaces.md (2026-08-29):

# 接口清单

更新时间：2026-07-01

本文按当前代码实现整理所有对外接口，覆盖 Web 控制台、deskbot 设备服务、paddlespeech TTS 侧车。重点列 HTTP / WebSocket 路由、鉴权、主要参数与返回用途；ESP32 pb 字段细节见 [esp32_pb_protocol.md](./esp32_pb_protocol.md)。

## 服务与端口

| 服务 | 默认地址 | 实现位置 | 说明 |
|---|---|---|---|
| Web 控制台 | `http://<host>:5050` | `deskbot_server.web` | Flask 页面、用户登录、设备/记忆/模型管理、调试页、代理到设备服务 |
| deskbot 设备服务 | `ws://<host>:9000` / `http://<host>:9000` | `deskbot_server.ws` | ESP32 主链路、调试订阅、设备下发、轻量 HTTP API |
| paddlespeech TTS 侧车 | `ws://<host>:8092` | `paddlespeech_server` | 官方流式 TTS 与音素对齐 TTS |

## 鉴权约定

### Web 控制台 `:5050`

| 范围 | 鉴权 |
|---|---|
| `/`、`/login`、`/register`、`/health`、`/static/*` | 公开 |
| 其它页面 | 需要 Flask 登录态；未登录重定向到 `/login` |
| `/api/*` | 需要 Flask 登录态；未登录返回 `401 {"ok": false, "error": "unauthorized"}` |
| `/proxy/deskbot/*` | 需要登录态，并按当前用户绑定设备过滤/补全 `device_id` |

### deskbot 设备服务 `:9000`

| 范围 | 鉴权 |
|---|---|
| `GET /health` | 公开 |
| `/api/*` | 需要 API Key；支持查询参数 `api_key` / `apikey` / `key`，Header `X-API-Key`，或 `Authorization: Bearer <key>` |
| `/asr_chat` | 需要 API Key |
| `/device_pipeline` 生产者 | 需要 API Key |
| `/device_pipeline` 订阅者、`/camera_view` | API Key 或 Web 控制台签发的 `debug_token` |

常见错误：无 Key 为 `401` 或 WS close `1008 api_key_required`；免费 Key 超额为 `429` 或 WS close `1008 quota_exhausted`；用户 Key 操作未绑定设备为 `403 forbidden_device`。

## Web 控制台页面与表单 `:5050`

### 公开与账号

| 方法 | 路径 | 用途 | 主要输入 |
|---|---|---|---|
| GET | `/` | 站点首页；已登录时跳转 `/home` | - |
| GET | `/login` | 登录页 | `next` query |
| POST | `/login` | 登录提交 | form: `email`, `password`, `next` |
| GET | `/register` | 注册页 | - |
| POST | `/register` | 注册提交并登录 | form: `email`, `password`, `confirm_password` |
| POST | `/logout` | 退出登录 | - |
| GET | `/health` | Web 控制台健康检查 | 返回纯文本 `ok` |

### 2C 用户页面

| 方法 | 路径 | 用途 |
|---|---|---|
| GET | `/home` | 2C 首页 |
| GET | `/voice` | 语音设置/入口 |
| GET | `/expr` | 表情设置/入口 |
| GET | `/my/memories` | 我的记忆 |
| GET | `/my/reminders` | 我的提醒 |
| GET | `/my/people` | 我的人物/人脸 |
| GET | `/my/devices` | 我的设备 |
| GET | `/advanced` | 高级设置 |

### 管理后台页面

| 方法 | 路径 | 用途 |
|---|---|---|
| GET | `/app/` | 工作台 |
| GET | `/app/devices` | 设备管理 |
| GET | `/app/scheduled-tasks` | 定时任务列表 |
| GET | `/app/face-profiles` | 人脸档案 |
| GET | `/app/memories` | 长期记忆 |
| GET | `/app/llm-models` | LLM 模型配置 |
| GET | `/app/usage` | 用量看板 |
| GET | `/app/settings` | 账号设置/API Key |
| POST | `/app/settings/profile` | 更新显示名 | form: `display_name` |
| POST | `/app/settings/password` | 修改密码 | form: `old_password`, `new_password`, `confirm_password` |
| POST | `/app/settings/api-keys` | 创建 API Key | form: `key_name` |
| POST | `/app/settings/api-keys/{key_id}/revoke` | 吊销 API Key | path: `key_id` |

### 调试页面

| 方法 | 路径 | 用途 |
|---|---|---|
| GET | `/debug/devices` | 在线设备、流水线、表情/舵机调试 |
| GET | `/debug/tts` | 豆包 TTS 调试 |
| GET | `/debug/llm` | LLM 试聊与 system prompt |
| GET | `/debug/paddlespeech` | PaddleSpeech 音素 TTS 调试 |
| GET | `/debug/simulation` | 模拟对话/显示调试 |

## Web 控制台 JSON API `:5050`

### 2C 高级设置

| 方法 | 路径 | 用途 | 主要输入 |
|---|---|---|---|
| GET | `/api/advanced` | 汇总当前用户、设备、用量、API Key、LLM 配置 | - |
| PATCH | `/api/advanced/profile` | 更新显示名 | JSON: `display_name` |
| POST | `/api/advanced/password` | 修改密码 | JSON: `old_password`, `new_password`, `confirm_password` |
| POST | `/api/advanced/api-keys` | 创建 API Key | JSON: `name` |
| DELETE | `/api/advanced/api-keys/{key_id}` | 吊销 API Key | path: `key_id` |
| GET | `/api/emotion_expr_map` | 读取情绪到表情映射 | query: `device_id` 可选，默认当前设备 |
| POST | `/api/emotion_expr_map` | 保存情绪到表情映射 | JSON: `map` |

### 管理后台数据 API

| 方法 | 路径 | 用途 | 主要输入 |
|---|---|---|---|
| GET | `/app/api/devices` | 当前用户绑定设备列表 | - |
| POST | `/app/api/devices` | 绑定设备并设为当前设备 | JSON/form: `device_id`, JSON: `display_name` 可选 |
| POST | `/app/api/devices/select` | 切换当前设备；空 `device_id` 清空选择 | JSON: `device_id` |
| DELETE | `/app/api/devices/{device_id}` | 解绑设备 | path: `device_id` |
| GET | `/app/api/scheduled-tasks` | 查询设备定时任务 | query: `device_id` 可选，默认当前设备 |
| DELETE | `/app/api/scheduled-tasks/{task_id}` | 删除定时任务 | path: `task_id`, query: `device_id` 可选 |
| GET | `/app/api/face-profiles` | 查询人脸档案摘要 | query: `device_id` 可选 |
| PUT/PATCH | `/app/api/face-profiles/{person_id}` | 更新人脸名称 | JSON: `name`, query: `device_id` 可选 |
| DELETE | `/app/api/face-profiles/{person_id}` | 删除人脸档案 | path: `person_id`, query: `device_id` 可选 |
| GET | `/app/api/memories` | 查询长期记忆 | query: `device_id` 可选 |
| POST | `/app/api/memories` | 新增长期记忆 | JSON/form: `text` |
| GET | `/app/api/memories/{entry_id}` | 查询单条记忆 | path: `entry_id` |
| PUT/PATCH | `/app/api/memories/{entry_id}` | 更新记忆文本 | JSON: `text` |
| DELETE | `/app/api/memories/{entry_id}` | 删除记忆 | path: `entry_id` |
| GET | `/app/api/llm-models` | 查询设备 LLM 模型列表与当前生效配置 | query: `device_id` 可选 |
| POST | `/app/api/llm-models` | 新增设备 LLM 模型 | JSON: `name`, `model_name`, `protocol`, `base_url`, `api_key` |
| PUT | `/app/api/llm-models/{model_id}` | 更新设备 LLM 模型 | JSON: `name`, `model_name`, `protocol`, `base_url`, `api_key` 可选 |
| DELETE | `/app/api/llm-models/{model_id}` | 删除设备 LLM 模型 | path: `model_id` |
| POST | `/app/api/llm-models/select` | 选择/清空当前 LLM 模型 | JSON: `model_id`，可为 `null` |

这些接口均会校验当前用户是否拥有目标 `device_id`。未选设备返回 `400`，设备不属于当前用户返回 `403`。

### Web 调试 API

| 方法 | 路径 | 用途 | 主要输入 |
|---|---|---|---|
| GET | `/api/debug/ws_token` | 为已登录用户签发调试 WebSocket `debug_token` | - |
| GET | `/api/doubao_tts/speakers` | 豆包 TTS 说话人预设 | - |
| GET | `/api/doubao_tts/config` | 读取豆包 TTS 配置，密钥脱敏 | - |
| POST | `/api/doubao_tts/config` | 保存豆包 TTS 配置 | JSON: `api_key`, `speaker`, `resource_id`, `model`, `ws_url`, `sample_rate`, `audio_format` |
| POST | `/api/doubao_tts/synthesize` | 豆包 TTS 合成并返回 WAV base64 | JSON: `text`，可带临时 TTS 配置 |
| POST | `/api/paddlespeech/phoneme_tts` | 代理调用音素 TTS，返回分片与 WAV base64 | JSON: `text`, `spk_id` |
| GET | `/api/llm/system_prompt` | 读取设备 LLM system prompt | query/body/session: `device_id` |
| POST | `/api/llm/system_prompt` | 保存设备 LLM system prompt | JSON: `system_prompt` 或 `content`, `device_id` 可选 |
| POST | `/api/llm/chat` | 调试 LLM 对话，不直接走设备 ASR | JSON: `text`, `history`, `system_prompt`, `temperature`, `device_id`, `device_context` |
| GET | `/api/servo_config` | 读取舵机配置 | query/session: `device_id` |
| POST | `/api/servo_config` | 保存舵机配置 | JSON: servo 文档 |
| GET | `/api/camera_face_config` | 读取相机人脸检测配置 | query/session: `device_id` |
| POST | `/api/camera_face_config` | 保存相机人脸检测配置 | JSON: camera face 文档 |
| GET | `/api/face_profiles` | 读取人脸档案原始文件 | query/session: `device_id` |
| POST | `/api/face_profiles/register` | 绑定当前检测到的人脸为档案 | JSON: `device_id`, `face_id`, `name` |
| GET | `/api/user_memory` | 读取设备长期记忆原始列表 | query/session: `device_id` |
| POST | `/api/user_memory` | 新增长期记忆 | JSON: `text`, `device_id` 可选 |
| DELETE | `/api/user_memory/{entry_id}` | 删除长期记忆 | path: `entry_id`, query/session: `device_id` |
| GET | `/api/face_mouth_by_phoneme` | 读取音素口型组表 | query/session: `device_id` |
| POST | `/api/face_mouth_by_phoneme` | 保存音素口型组表 | JSON: 组表数组或文档 |
| GET | `/api/face_expr_scenes` | 读取表情场景配置 | query/session: `device_id` |
| POST | `/api/face_expr_scenes` | 保存表情场景配置 | JSON: 场景数组 |
| GET | `/api/scene_playbooks` | 读取场景 playbook 配置 | query/session: `device_id` |
| POST | `/api/scene_playbooks` | 保存场景 playbook 配置 | JSON: playbook 数组 |
| GET | `/api/health` | 检查 deskbot-server 与 TTS 端口是否可连 | - |

### 代理 API

| 方法 | 路径 | 用途 |
|---|---|---|
| GET/POST/PUT/DELETE/OPTIONS | `/proxy/deskbot/{subpath}` | 登录用户访问 `:9000` HTTP API 的代理入口；会过滤 `/api/devices`，并对需要设备的路径校验/补全当前 `device_id` |

代理会将请求转发到 `deskbot_upstream_base()`，并尽量附带服务器保存的免费 API Key。当前设备相关的代理路径包括 `/api/device_servo`、`/api/device_tts`、`/api/device_pb_scene`、`/api/device_pb_anim`、`/api/device_pb_expr_scene`、`/api/device_pb_scenes`、`/api/scene_playbook/run`。

## deskbot WebSocket `:9000`

### `/asr_chat`

生产设备主链路。默认 URL：

```text
ws://<host>:9000/asr_chat?device_id=<id>&api_key=<key>
```

`device_id` 别名：`device_id`、`deviceid`、`device`、`id`。连接成功后服务端发送：

```json
{"type": "ready", "device_id": "<id>"}
```

设备上行消息：

| 方向 | 消息 | binary | 用途 |
|---|---|---|---|
| 设备 -> 服务端 | `{"type":"audio","codec":"opus|pcm16","next_bin_len":N}` | 下一帧为音频 | 输入语音；也兼容 `data` base64 或裸 binary |
| 设备 -> 服务端 | `{"type":"flush"}` | 无 | 结束当前语音段，触发 ASR/LLM/TTS |
| 设备 -> 服务端 | `{"type":"camera_frame","codec":"jpeg","next_bin_len":N,"seq":...}` | 下一帧为 JPEG | 上传画面用于人脸检测、预览、跟随 |
| 设备 -> 服务端 | `{"type":"pb_ack", ...}` | 无 | 播放回压与状态上报；会进入设备流水线订阅 |
| 设备 -> 服务端 | `{"type":"user_text","text":"..."}` | 无 | 调试：跳过 ASR，直接进入对话 |
| 设备 -> 服务端 | `{"type":"ping"}` | 无 | 保活；非 pb-only 模式回 `pong` |

服务端下行消息：

| 消息 | binary | 用途 |
|---|---|---|
| `pb_start` / `pb_chunk` / `pb_end` | 可选，取决于 `audio.next_bin_len` | 多片 pb 下发，含 PCM、表情、舵机 |
| `pb_single` | 可选 | 单片 pb 下发 |
| `face_info` | 无 | 仅 `send_face_info_to_asr_chat=true` 且非 pb-only 时可能下发 |
| `ready` / `pong` / 错误类 JSON | 无 | 握手、保活、异常提示 |

默认 `asr_chat_device_pb_only: true`，设备端应只依赖 `pb_*` + PCM。pb wire 规则见 [esp32_pb_protocol.md](./esp32_pb_protocol.md)。

### `/camera_view`

调试 JPEG 预览订阅。URL：

```text
ws://<host>:9000/camera_view?device_id=<id>&api_key=<key>
ws://<host>:9000/camera_view?device_id=<id>&debug_token=<token>
```

| 方向 | 消息 | 用途 |
|---|---|---|
| 服务端 -> 客户端 | `{"type":"ready","channel":"camera_view","device_filter":"...","expects":"binary JPEG frames preceded by camera_frame meta"}` | 订阅就绪 |
| 服务端 -> 客户端 | `{"type":"camera_frame", ...}` + 下一帧 JPEG binary | 最新相机帧与检测元数据 |
| 客户端 -> 服务端 | `{"type":"ping"}` | 服务端回 `{"type":"pong"}` |

### `/device_pipeline`

流水线事件通道，支持生产者与订阅者两种角色。

生产者 URL：

```text
ws://<host>:9000/device_pipeline?device_id=<id>&api_key=<key>
```

订阅者 URL：

```text
ws://<host>:9000/device_pipeline?role=subscriber&device_id=<id>&api_key=<key>
ws://<host>:9000/device_pipeline?role=subscriber&device_id=<id>&debug_token=<token>
```

订阅者 `role` 支持 `subscriber`、`sub`、`viewer`、`consumer`；`device_id` 可省略，省略时订阅全部设备。

| 角色 | 方向 | 消息 | 用途 |
|---|---|---|---|
| 全部 | 服务端 -> 客户端 | `{"type":"ready","channel":"device_pipeline",...}` | 通道就绪 |
| 订阅者 | 服务端 -> 客户端 | `{"type":"pipeline_snapshot","items":[...],"device_filter":...,"max_events":100}` | 连接时快照 |
| 订阅者 | 服务端 -> 客户端 | `{"type":"pipeline_event","event":{...}}` | 一轮 ASR/LLM/TTS 或自动下发事件 |
| 订阅者 | 服务端 -> 客户端 | `{"type":"pipeline_stage","event":{...}}` | 阶段事件，例如 `pb_ack`、`face_pos` |
| 生产者 | 客户端 -> 服务端 | 任意 JSON 事件，含 `asr_text`、`llm_text`、`tts_text`、耗时、状态等 | 归一化后写入流水线窗口 |
| 生产者 | 服务端 -> 客户端 | `{"type":"pipeline_ack","seq":N}` | 事件已接收 |
| 生产者 | 服务端 -> 客户端 | `{"type":"pipeline_rejected","reason":"invalid_payload"}` | 事件无效 |
| 全部 | 客户端 -> 服务端 | `{"type":"ping"}` | 服务端回 `pong` |

### `/camera`

旧独立相机通道已移除。连接会收到错误消息并以 close code `1008` 关闭，应改用 `/asr_chat` 的 `camera_frame`。

## deskbot HTTP API `:9000`

所有 `/api/*` 均支持 `OPTIONS` CORS 预检。除 `/health` 外，均需 API Key。

| 方法 | 路径 | 用途 | 主要输入 |
|---|---|---|---|
| GET | `/health` | 存活探针 | - |
| GET | `/api/devices` | 当前在线设备列表；用户 Key 会按绑定设备过滤 | - |
| GET | `/api/asr_auto_reply` | 查询/设置 ASR 自动应答开关 | query: `enabled=1|0|true|false` 可选 |
| GET | `/api/pb_idle_auto_dispatch` | 查询/设置空闲 pb 自动下发开关 | query: `enabled=1|0|true|false` 可选 |
| GET | `/api/camera_servo_auto_mode` | 查询/设置相机舵机自动模式 | query: `mode=follow|follow_frontal|gaze|off` 可选 |
| GET | `/api/debug_prefs` | 查询/批量设置调试偏好 | query: `asr_auto_reply`, `camera_servo_auto_mode` 可选 |
| GET | `/api/pipeline_recent` | 获取流水线事件滚动窗口 | query: `device_id` 可选，`limit` 默认最多 100 |
| GET | `/api/device_servo` | 向设备 `/asr_chat` 下发单片舵机 pb | query: `device_id`, `dyaw`, `dpitch`, `ms`, `xm`, `ym`, `action`, `level`, `with_scene`/`append_scene` |
| GET | `/api/device_pb_scenes` | 列出内置/配置的 pb 场景名 | - |
| GET/POST | `/api/device_tts` | 跳过 LLM，直接 TTS 并下发到设备 | query 或 JSON: `device_id`, `text`, `scene` 可选 |
| GET/POST | `/api/scene_playbook/run` | 执行场景 playbook，并与 TTS/表情/舵机交错下发 | GET: `device_id`, `name`; POST JSON: `device_id`, `playbook` 或 `name` |
| GET | `/api/device_pb_scene` | 按场景名向设备顺序下发 `pb_start -> pb_chunk* -> pb_end` | query: `device_id`, `scene` |
| GET/POST | `/api/servo_config` | 读取/写入舵机配置文件 | query/JSON: `device_id` 可选；POST body 为 servo 文档 |
| GET/POST | `/api/face_mouth_by_phoneme` | 读取/写入音素口型组表 | query/JSON: `device_id` 可选；POST body 为组表 |
| GET/POST | `/api/device_pb_anim` | 下发仅含 `anim` 的单片 `pb_single` | GET: `device_id`, `anim_b64`, `chunk_ms`, `action`, `level`; POST JSON: `device_id`, `anim`, `chunk_ms`, `action`, `level` |
| GET/POST | `/api/face_expr_scenes` | 读取/写入设计表情场景 | query/JSON: `device_id` 可选；POST body 为场景数组 |
| GET | `/api/device_pb_expr_scene` | 按设计表情场景名向设备下发 pb 链 | query: `device_id`, `scene` 或 `name` |

未知 `/api/*` 返回 `404 {"error":"not found","path":"..."}`。不支持的方法返回 `405`。

## paddlespeech WebSocket `:8092`

### `/paddlespeech/tts/streaming`

PaddleSpeech 官方流式 TTS WebSocket，由 `paddlespeech.server.ws.api.setup_router` 根据配置 `engine_list: ['tts_online-onnx']` 注册。本项目未修改该协议；deskbot 默认通过 `config.yaml -> tts.ws_url` 连接它。

### `/paddlespeech/tts/streaming_phoneme`

音素分片 TTS，供口型对齐使用。传输为 WebSocket JSON 文本帧。

请求流程：

| 步骤 | 客户端消息 | 服务端响应 |
|---|---|---|
| 开始 | `{"signal":"start"}` | `{"status":0,"signal":"server ready","session":"..."}` |
| 合成 | `{"text":"你好","spk_id":0}` | `{"status":1,"segments":[...]}`，随后 `{"status":2,"segments":[]}` |
| 结束 | `{"signal":"end","session":"..."}` | `{"status":0,"signal":"connection will be closed","session":"..."}` |

`segments[]` 字段：

| 字段 | 说明 |
|---|---|
| `phoneme_id` | PaddleSpeech 音素 ID |
| `phoneme` | 音素符号 |
| `ms` | 该分片估算时长，毫秒 |
| `audio` | 小端 int16 PCM 分片的 base64 |

错误响应：

```json
{"status": -1, "message": "...", "segments": []}
```

常见错误包括 `send signal start first`、`empty text`、`empty phone_ids for text`、`invalid request json`。

## 源码索引

| 范围 | 文件 |
|---|---|
| Flask app 注册与全局鉴权 | `service/deskbot-server/src/deskbot_server/web/app.py` |
| Web 控制台账号路由 | `service/deskbot-server/src/deskbot_server/web/blueprints/auth_bp.py` |
| Web 管理后台路由 | `service/deskbot-server/src/deskbot_server/web/blueprints/app_bp.py` |
| 2C 页面/API 路由 | `service/deskbot-server/src/deskbot_server/web/blueprints/app2c_bp.py` |
| Web 调试路由 | `service/deskbot-server/src/deskbot_server/web/blueprints/debug_bp.py` |
| Web 到 deskbot 代理 | `service/deskbot-server/src/deskbot_server/web/blueprints/proxy_bp.py` |
| deskbot WS 路由分发 | `service/deskbot-server/src/deskbot_server/ws/router.py` |
| deskbot HTTP API | `service/deskbot-server/src/deskbot_server/ws/http_api.py` |
| `/asr_chat` 协议 | `service/deskbot-server/src/deskbot_server/ws/asr_chat.py` |
| `/device_pipeline` 协议 | `service/deskbot-server/src/deskbot_server/ws/device_pipeline.py` |
| `/camera_view` 协议 | `service/deskbot-server/src/deskbot_server/ws/camera.py` |
| TTS 侧车入口 | `service/paddlespeech-server/src/paddlespeech_server/main.py` |
| 音素 TTS 路由 | `service/paddlespeech-server/src/paddlespeech_server/ws_phoneme.py` |

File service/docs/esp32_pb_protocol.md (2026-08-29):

# ESP32 与 BotServer 通信协议（pb v2.1）

单条 WebSocket：`ws://<host>:9000/asr_chat?device_id=<id>&api_key=<key>`。文本 JSON 与 binary 交替，**不用 base64**。长度由 **`next_bin_len`** 声明（上行在 JSON 根；下行在 `audio.next_bin_len`）。旧版 `audio.next_bin: 1` 已废弃。

> **相关文档：** 部署与快速使用见 [README.md](../README.md)；主服务配置见 [SERVER.md](./SERVER.md)。定时任务、长期记忆、控制台管理等为**服务端能力**，不扩展本设备协议字段。

默认 **`asr_chat_device_pb_only: true`**：设备下行只处理 **`pb_*` + PCM**。服务端不再下发 `face_info`、`asr_*`、`llm_text`、TTS/错误类 JSON（如 `playback_done`、`tts_error`、`error`、`asr_rejected` 等）；轮次结果与耗时见 `/device_pipeline` 的 `pipeline_event` 或 Web 调试台。

---

## 0. 鉴权与配额（设备端必读）

### 0.1 适用范围

| 通道 | 路径 | 是否需要 API Key |
|---|---|---|
| 生产主链路 | `/asr_chat` | **必须** |
| 摄像头预览 | `/camera_view` | **必须** |
| 流水线订阅 | `/device_pipeline` | **必须** |
| HTTP API | `/api/*`（非本机） | **必须** |
| 健康检查 | `/health` | 否 |

本机调试代理（Flask `:5050` → deskbot）从 `127.0.0.1` 转发时免 Key；**ESP32 直连 `:9000` 必须携带 Key**。

### 0.2 传递方式（二选一）

**方式 A — URL 查询参数（推荐固件实现）**

```
ws://<host>:9000/asr_chat?device_id=deskbot_abc123&api_key=odk_xxxxxxxx
```

别名也支持：`apikey`、`key`。

**方式 B — WebSocket 握手 Header**

```
X-API-Key: odk_xxxxxxxx
```

或 `Authorization: Bearer odk_xxxxxxxx`。

### 0.3 Key 类型

| 类型 | 前缀 | 说明 |
|---|---|---|
| 用户 Key | `odk_` | 控制台「账号设置」生成，配额不限（默认） |
| 免费 Key | `odk_free_` | 服务器 `data/.free_api_key`，**每日 1GB 总字节** |
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

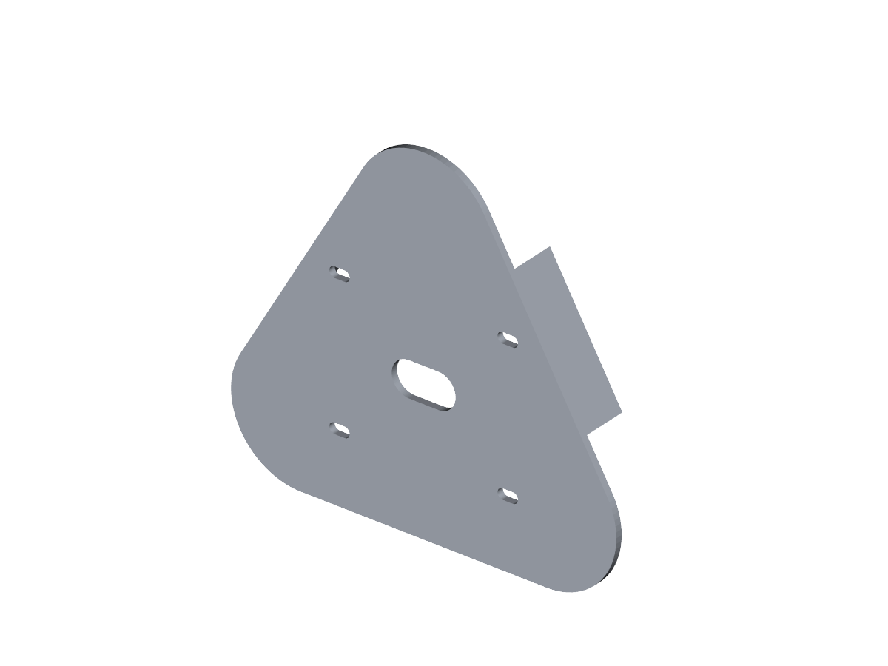
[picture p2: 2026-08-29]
hardware/mobile_base/mechanical/preview/N3_upper_cowl_v0_1_render.png

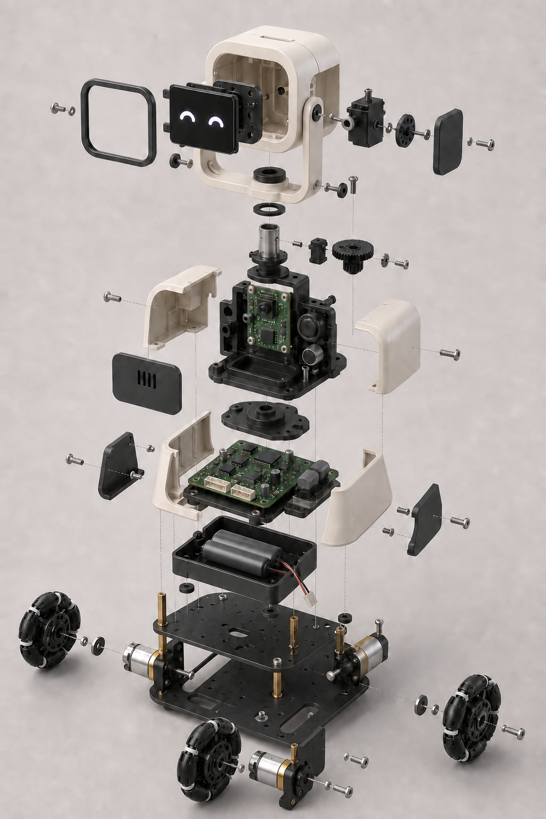
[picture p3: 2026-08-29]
hardware/mobile_base/mechanical/concept/Brufik_N3_exploded_concept_v0_1.png

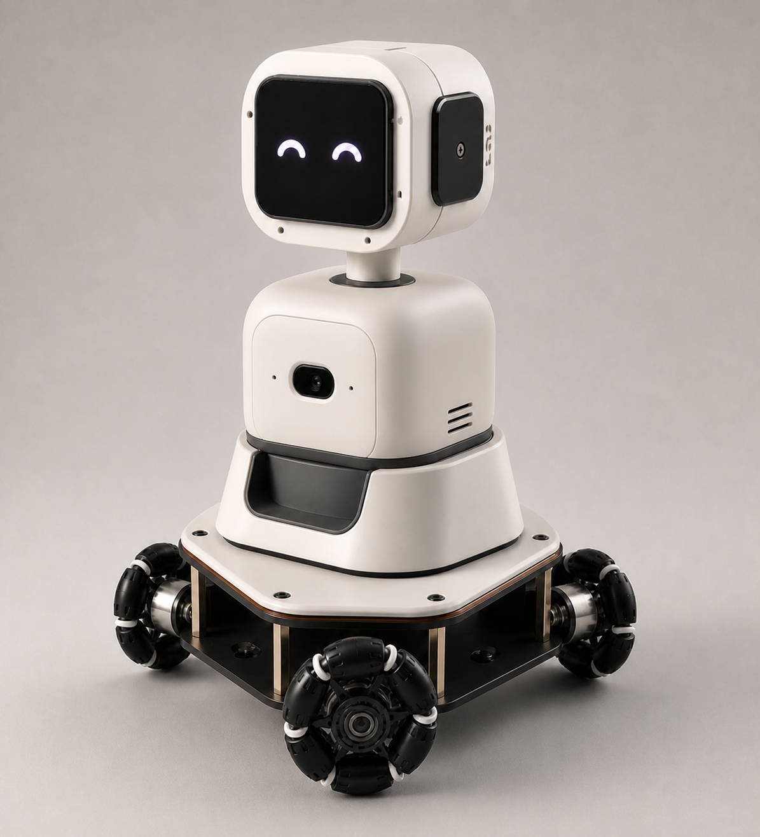
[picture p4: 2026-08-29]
hardware/mobile_base/mechanical/concept/Brufik_N3_upper_body_shell_concept_v0_5.png

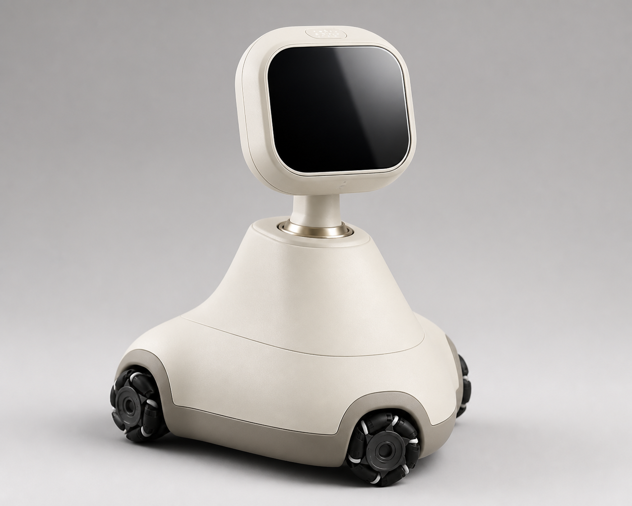
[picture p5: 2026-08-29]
hardware/mobile_base/mechanical/concept/Brufik_N3_full_enclosure_concept_v0_2.png

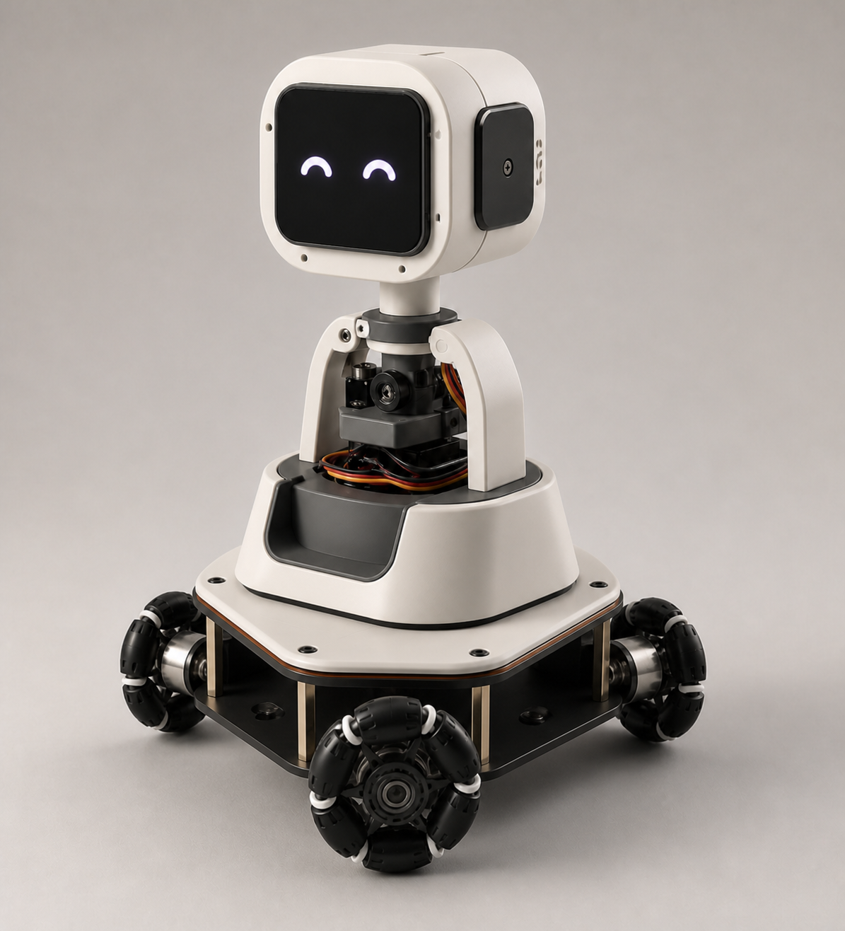
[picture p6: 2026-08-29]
hardware/mobile_base/mechanical/concept/Brufik_N3_triangular_chassis_concept_v0_4.png

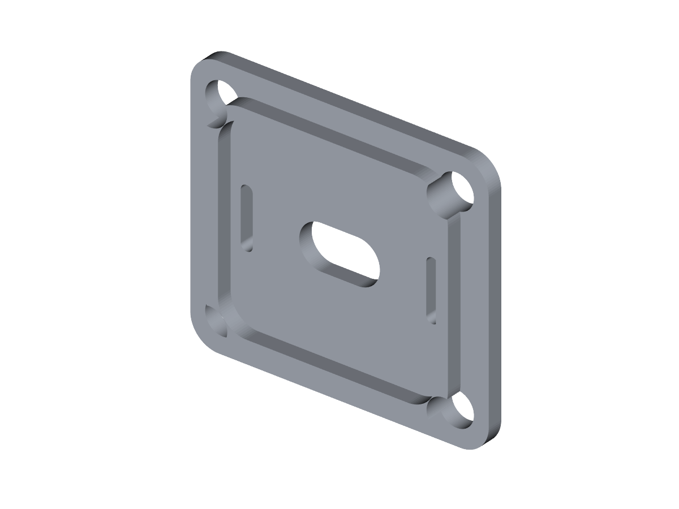
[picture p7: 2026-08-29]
hardware/mobile_base/mechanical/preview/Brufik_to_N3_adapter_v0_1_render.png

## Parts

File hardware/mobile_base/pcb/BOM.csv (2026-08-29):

Reference | Value | Footprint | Description | LCSC | Assembly
U1 | TPS54302DDCR | SOT-23-6 | 5V/3A synchronous buck | C129704 | SMT
U2 | DRV8833PWPR | HTSSOP-16-EP | Dual H-bridge for M1/M2 |  | SMT
U3 | DRV8833PWPR | HTSSOP-16-EP | Dual H-bridge for M3 |  | SMT
U4 | Seeed XIAO ESP32-C3 | XIAO-2x7-P2.54 | Base motion MCU |  | HAND
F1 | 5A resettable fuse | PTC-2920 | Battery branch protection |  | SMT
D1 | SMBJ10A | SMB | Battery transient suppressor | C83357 | SMT
L1 | 10uH 4A shielded | IND-7x7 | 5V buck output inductor |  | SMT
C1 | 22uF 16V X7R | C1210 | Buck input capacitor |  | SMT
C2 | 100nF 25V X7R | C0805 | Buck HF input bypass |  | SMT
C3 | 22uF 10V X7R | C1210 | 5V output capacitor |  | SMT
C4 | 22uF 10V X7R | C1210 | 5V output capacitor |  | SMT
C5 | 100nF 16V X7R | C0805 | TPS54302 bootstrap capacitor |  | SMT
C6 | 75pF C0G | C0805 | 5V feedback feed-forward capacitor |  | SMT
C7 | 470uF 16V low-ESR | CP-RADIAL-D8 | Motor/battery local bulk |  | HAND
C8 | 1000uF 10V low-ESR | CP-RADIAL-D10 | Upper-body 5V surge bulk |  | HAND
C9 | 10uF 16V X7R | C1210 | U2 VM local bypass |  | SMT
C10 | 2.2uF 10V X7R | C0805 | U2 VINT bypass |  | SMT
C11 | 10nF 16V X7R | C0805 | U2 VCP capacitor |  | SMT
C12 | 10uF 16V X7R | C1210 | U3 VM local bypass |  | SMT
C13 | 2.2uF 10V X7R | C0805 | U3 VINT bypass |  | SMT
C14 | 10nF 16V X7R | C0805 | U3 VCP capacitor |  | SMT
C15 | 100nF 25V X7R | C0805 | M1 EMI capacitor |  | SMT
C16 | 100nF 25V X7R | C0805 | M2 EMI capacitor |  | SMT
C17 | 100nF 25V X7R | C0805 | M3 EMI capacitor |  | SMT
R1 | 100k 1% | R0805 | 5V feedback upper resistor |  | SMT
R2 | 13.3k 1% | R0805 | 5V feedback lower resistor |  | SMT
R3 | 100k 1% | R0805 | Buck enable upper resistor |  | SMT
R4 | 47k 1% | R0805 | Buck enable lower resistor |  | SMT
R5 | 10k | R0805 | DRV nSLEEP pull-up |  | SMT
R7 | 0.20R 1W 1% | R2512 | M1 current limit, about 1A |  | SMT
R8 | 0.20R 1W 1% | R2512 | M2 current limit, about 1A |  | SMT
R9 | 0.20R 1W 1% | R2512 | M3 current limit, about 1A |  | SMT
J1 | BATTERY 2S | TERM-2P-P5.08 | Protected 2S battery input |  | HAND
J2 | POWER SWITCH | JST-XH-2P | External latching switch or jumper |  | HAND
J3 | MOTOR 1 | JST-XH-2P | N20 motor 1 |  | HAND
J4 | MOTOR 2 | JST-XH-2P | N20 motor 2 |  | HAND
J5 | MOTOR 3 | JST-XH-2P | N20 motor 3 |  | HAND
J6 | UPPER LINK | JST-XH-4P | 5V/GND/TX/RX to current robot |  | HAND
J7 | TOUCH | JST-XH-3P | 3.3V/GND/touch signal |  | HAND

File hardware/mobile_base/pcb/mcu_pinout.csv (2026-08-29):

XIAO Pin | Net | Description
D0 | M1_IN2 | Motor 1 direction/PWM B
D1 | M1_IN1 | Motor 1 direction/PWM A
D2 | M2_IN1 | Motor 2 direction/PWM A
D3 | M2_IN2 | Motor 2 direction/PWM B
D4 | M3_IN1 | Motor 3 direction/PWM A
D5 | M3_IN2 | Motor 3 direction/PWM B
D6 | UART_TX | Base TX to upper-body RX
D7 | UART_RX | Base RX from upper-body TX
D8 | SPARE | Reserved
D9 | SPARE | Reserved
D10 | TOUCH | Digital touch input

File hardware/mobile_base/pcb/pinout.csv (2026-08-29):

Connector | Pin | Net | Description
J1 | 1 | BAT_RAW | 2S protected battery positive
J1 | 2 | GND | Battery negative
J2 | 1 | BAT_FUSED | To external latching switch
J2 | 2 | VBAT | Switched return; jumper J2 for bench test
J3 | 1/2 | M1_B/M1_A | N20 motor 1
J4 | 1/2 | M2_B/M2_A | N20 motor 2
J5 | 1/2 | M3_B/M3_A | N20 motor 3
J6 | 1 | +5V | 5V up to 3A for current robot
J6 | 2 | GND | Common ground
J6 | 3 | UART_TX | Base TX to upper RX
J6 | 4 | UART_RX | Base RX from upper TX
J7 | 1 | +3V3 | Touch module power
J7 | 2 | GND | Touch module ground
J7 | 3 | TOUCH | Digital touch output to XIAO D10

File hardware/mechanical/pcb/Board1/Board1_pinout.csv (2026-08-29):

Connector | Pin | Net | Connects_To | Notes
USB1 | VBUS | +5V | H4-1 / J3-2 / J4-2 | USB-C 供电
USB1 | GND | GND | 公共地
USB1 | CC1 | CC1 | R1-1 | 5.1k 下拉
USB1 | CC2 | CC2 | R2-1 | 5.1k 下拉
H3 | 1 | D0/I2S_DIN | J2-3 | MAX98357 DIN (GPIO1)
H3 | 2 | D1/LCD_CS | J1-5 | 屏幕 CS (GPIO2)
H3 | 3 | D2/LCD_DC | J1-6 | 屏幕 DC (GPIO3)
H3 | 4 | D3 | NC | 未使用
H3 | 5 | D4/I2S_LRC | J2-5 | MAX98357 LRC (GPIO5)
H3 | 6 | D5/I2S_BCLK | J2-4 | MAX98357 BCLK (GPIO6)
H3 | 7 | GND | GND | 公共地
H4 | 1 | +5V | USB1-VBUS | 5V 输入
H4 | 2 | +3V3 | J2-1 / J1-1 | 逻辑/屏幕 3.3V
H4 | 3 | D6/SERVO_Y | J4-3 | 上下舵机 PWM (GPIO43)
H4 | 4 | D7/SERVO_X | J3-3 | 左右舵机 PWM (GPIO44)
H4 | 5 | D8/LCD_SCK | J1-4 | 屏幕 SCK (GPIO7)
H4 | 6 | D9 | NC | 未使用
H4 | 7 | D10/LCD_MOSI | J1-3 | 屏幕 MOSI (GPIO9)
J2 | 1 | +3V3 | H4-2 | 功放板 3.3V
J2 | 2 | GND | GND | 功放板 GND
J2 | 3 | D0/I2S_DIN | H3-1 | 功放板 DIN
J2 | 4 | D5/I2S_BCLK | H3-6 | 功放板 BCLK
J2 | 5 | D4/I2S_LRC | H3-5 | 功放板 LRC
J2 | 6 | SPK+ | J1-7 | 功放板 SPK+
J2 | 7 | SPK- | J1-8 | 功放板 SPK-
J1 | 1 | +3V3 | H4-2 | 头部 3.3V
J1 | 2 | GND | GND | 头部 GND
J1 | 3 | D10/LCD_MOSI | H4-7 | 头部 MOSI
J1 | 4 | D8/LCD_SCK | H4-5 | 头部 SCK
J1 | 5 | D1/LCD_CS | H3-2 | 头部 CS
J1 | 6 | D2/LCD_DC | H3-3 | 头部 DC
J1 | 7 | SPK+ | J2-6 | 头部喇叭 +
J1 | 8 | SPK- | J2-7 | 头部喇叭 -
J3 | 1 | GND | GND | 舵机 GND (X)
J3 | 2 | +5V | USB1-VBUS | 舵机 5V (X)
J3 | 3 | D7/SERVO_X | H4-4 | 左右(X) PWM
J4 | 1 | GND | GND | 舵机 GND (Y)
J4 | 2 | +5V | USB1-VBUS | 舵机 5V (Y)
J4 | 3 | D6/SERVO_Y | H4-3 | 上下(Y) PWM

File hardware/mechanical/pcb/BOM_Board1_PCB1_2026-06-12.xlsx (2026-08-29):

No. | Quantity | Comment | Designator | Footprint | Value | Manufacturer Part | Manufacturer | Supplier Part | Supplier
1 | 2 | 5.1kΩ | 1K1,5.1k | R0805 | 5.1kΩ | 0805W8F5101T5E | UNI-ROYAL(厚声) | C27834 | LCSC
2 | 2 | PZ254V-11-07P | H3,H4 | HDR-TH_7P-P2.54-V-M |  | PZ254V-11-07P | XFCN(兴飞) | C492406 | LCSC
3 | 1 | TYPE-C 6P(073) | USB1 | TYPE-C-SMD_TYPE-C-6P-073 |  | TYPE-C 6P(073) | SHOU HAN(首韩) | C668623 | LCSC
4 | 1 | ZX-MX1.25-8PLT | vcc | CONN-SMD_8P-P1.25_ZX-MX1.25-8PLT |  | ZX-MX1.25-8PLT | Megastar(兆星) | C19272385 | LCSC
5 | 1 | PZ254R-11-07P | vin | HDR-TH_7P-P2.54-H-M-W10.4 |  | PZ254R-11-07P | XFCN(兴飞) | C492415 | LCSC
6 | 1 | PZ254R-11-03P | X舵机 | HDR-TH_3P-P2.54-H-M-W10.4 |  | PZ254R-11-03P | XFCN(兴飞) | C492411 | LCSC
7 | 1 | PZ254V-11-03P | Y舵机 | HDR-TH_3P-P2.54-V-M_PZ254V-11-03P |  | PZ254V-11-03P | XFCN(兴飞) | C2937625 | LCSC

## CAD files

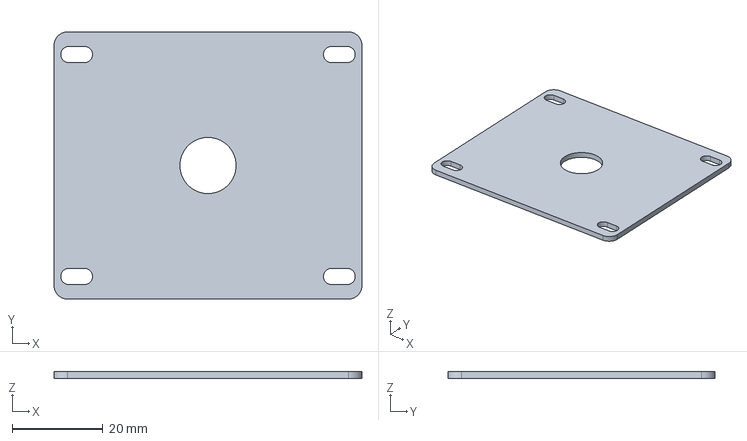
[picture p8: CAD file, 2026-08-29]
hardware/mobile_base/mechanical/export/N3_58x49_fit_jig_v0_1.step
68.0 x 59.0 x 1.60 mm

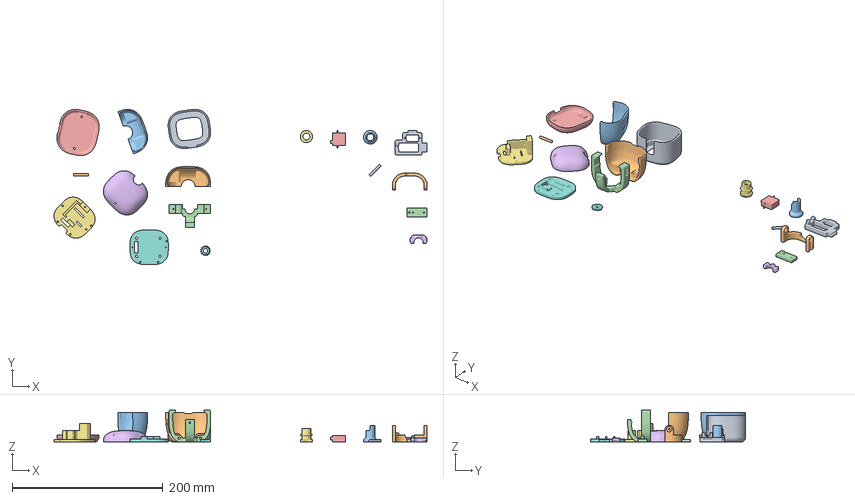
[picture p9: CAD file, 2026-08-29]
hardware/mechanical/print_ready/bambu_p2s/Brufik_P2S_two_plate_source.3mf
495.3 x 206.1 x 42.1 mm
06_头部前壳_Head_Front_Shell.stl
05_身体后壳_Body_Rear_Shell.stl
04_身体前壳_Body_Front_Shell.stl
03_身体主骨架_Body_Main_Frame.stl
01_底座_Base_Tray.stl
07_头部后壳_Head_Rear_Shell.stl
09_头部后内框_Head_Rear_Inner_Frame.stl
08_头部前内框_Head_Front_Inner_Frame.stl
02_底部舵机支架_Base_Servo_Mount.stl
10_头部U形支架_Head_U_Bracket.stl
13_颈部旋转轴套_Neck_Rotation_Coupler.stl
12_头部侧支架_Head_Side_Bracket.stl
11_头部竖向安装块_Head_Vertical_Mount.stl
16_小U形卡扣_Small_U_Clip.stl
14_颈部齿轮轴_Neck_Gear_Shaft.stl
15_传动小齿轮_Drive_Gear.stl
17_定位销A_Pin_A.stl
18_定位销B_Pin_B.stl

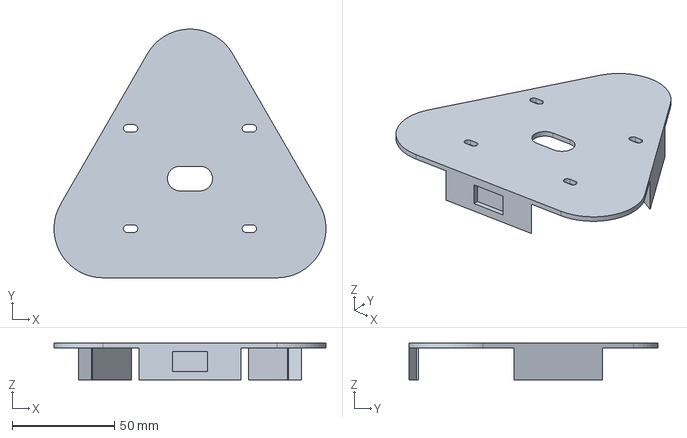
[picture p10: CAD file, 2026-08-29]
hardware/mobile_base/mechanical/export/N3_upper_cowl_v0_1.step
132.8 x 121.5 x 18.0 mm

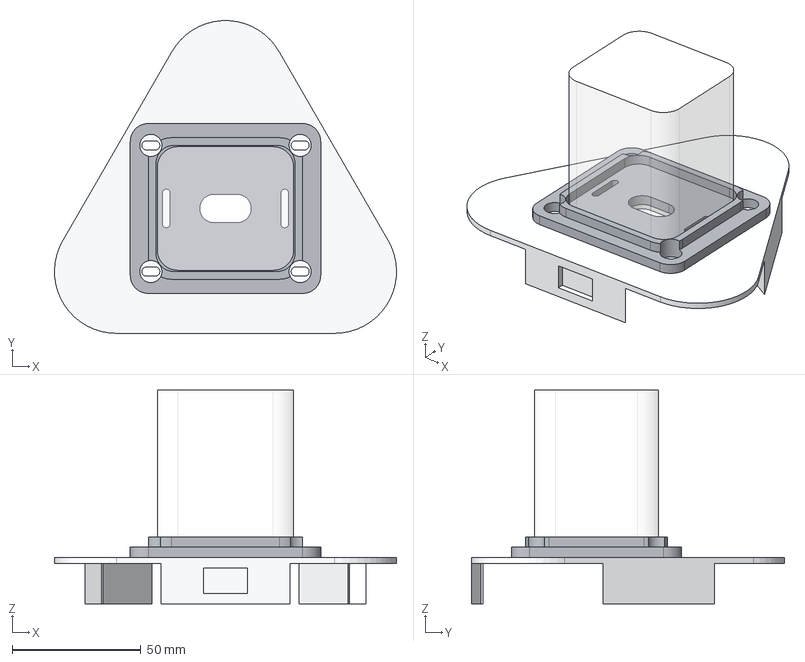
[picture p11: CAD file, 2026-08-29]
hardware/mobile_base/mechanical/export/Brufik_N3_mobile_base_v0_1.step
132.8 x 121.5 x 83.0 mm
N3 upper cowl_part
Brufik cradle_part
Brufik clearance envelope_part

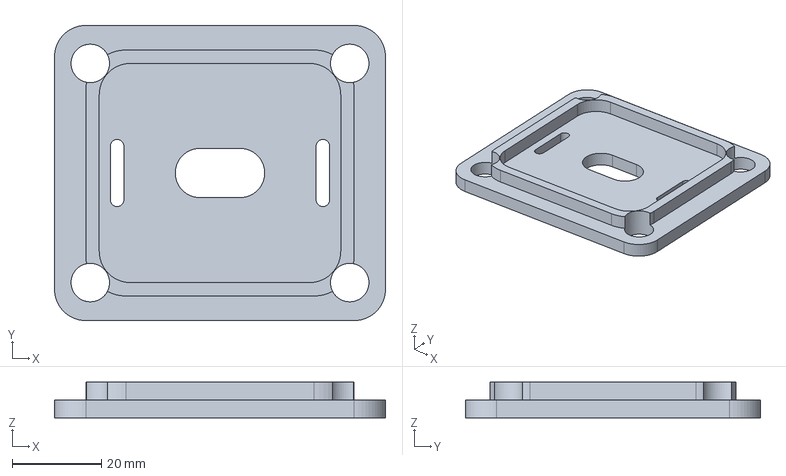
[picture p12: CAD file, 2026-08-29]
hardware/mobile_base/mechanical/export/Brufik_to_N3_adapter_v0_1.step
74.0 x 66.0 x 8.00 mm

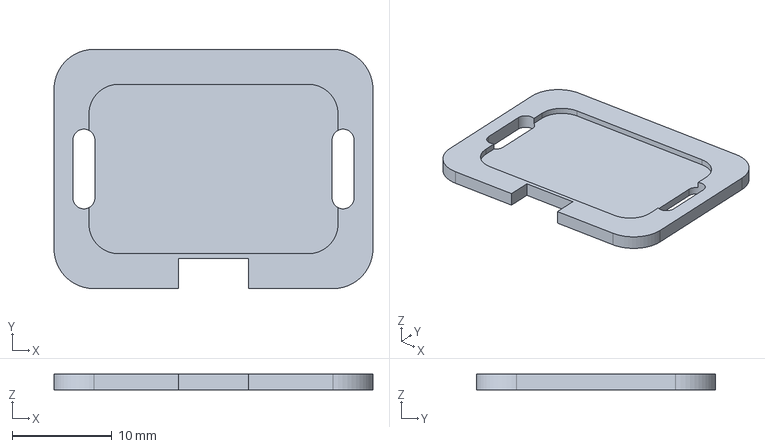
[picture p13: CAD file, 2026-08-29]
hardware/mobile_base/mechanical/export/Head_touch_electrode_holder_v0_1.step
32.0 x 24.0 x 1.60 mm

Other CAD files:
hardware/mechanical/print_ready/bambu_p2s/Brufik_P2S_plate_01_main_0.20mm_PLA.gcode.3mf
hardware/mechanical/print_ready/bambu_p2s/Brufik_P2S_plate_02_remaining_0.20mm_PLA.gcode.3mf
hardware/mobile_base/mechanical/export/Brufik_to_N3_adapter_v0_1.stl
hardware/mobile_base/mechanical/export/Head_touch_electrode_holder_v0_1.stl
hardware/mobile_base/mechanical/export/N3_58x49_fit_jig_v0_1.stl
hardware/mobile_base/mechanical/export/N3_upper_cowl_v0_1.stl

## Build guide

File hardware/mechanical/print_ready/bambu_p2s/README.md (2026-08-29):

# Brufik — Bambu Lab P2S 打印文件

本目录保存 Brufik 机身结构件的两盘 P2S 切片文件，以及可继续编辑的两盘 Bambu Studio 工程源文件。

## 打印配置

- 打印机：Bambu Lab P2S
- 喷嘴：0.4 mm
- 打印板：纹理 PEI
- 工艺预设：`0.20mm Standard @ BBL P2S`
- 耗材：Generic PLA
- 支撑：树状（自动），临界角 30°，不限于仅在热床上生成

## 文件

- `Brufik_P2S_plate_01_main_0.20mm_PLA.gcode.3mf`
  - 第一盘主要外壳与底座结构件
  - 210 层，切片估算 75.02 g，约 3 小时 3 分钟
- `Brufik_P2S_plate_02_remaining_0.20mm_PLA.gcode.3mf`
  - 第二盘剩余小件与机构件
  - 110 层，切片估算 12.17 g，约 44 分 51 秒
- `Brufik_P2S_two_plate_source.3mf`
  - 两盘可编辑工程；用于重新排版、改耗材或重新切片

`.gcode.3mf` 已包含切片后的 G-code，适用于上述打印机与配置。再次使用前，仍应在 Bambu Studio 中核对打印机、喷嘴、打印板和耗材是否一致。

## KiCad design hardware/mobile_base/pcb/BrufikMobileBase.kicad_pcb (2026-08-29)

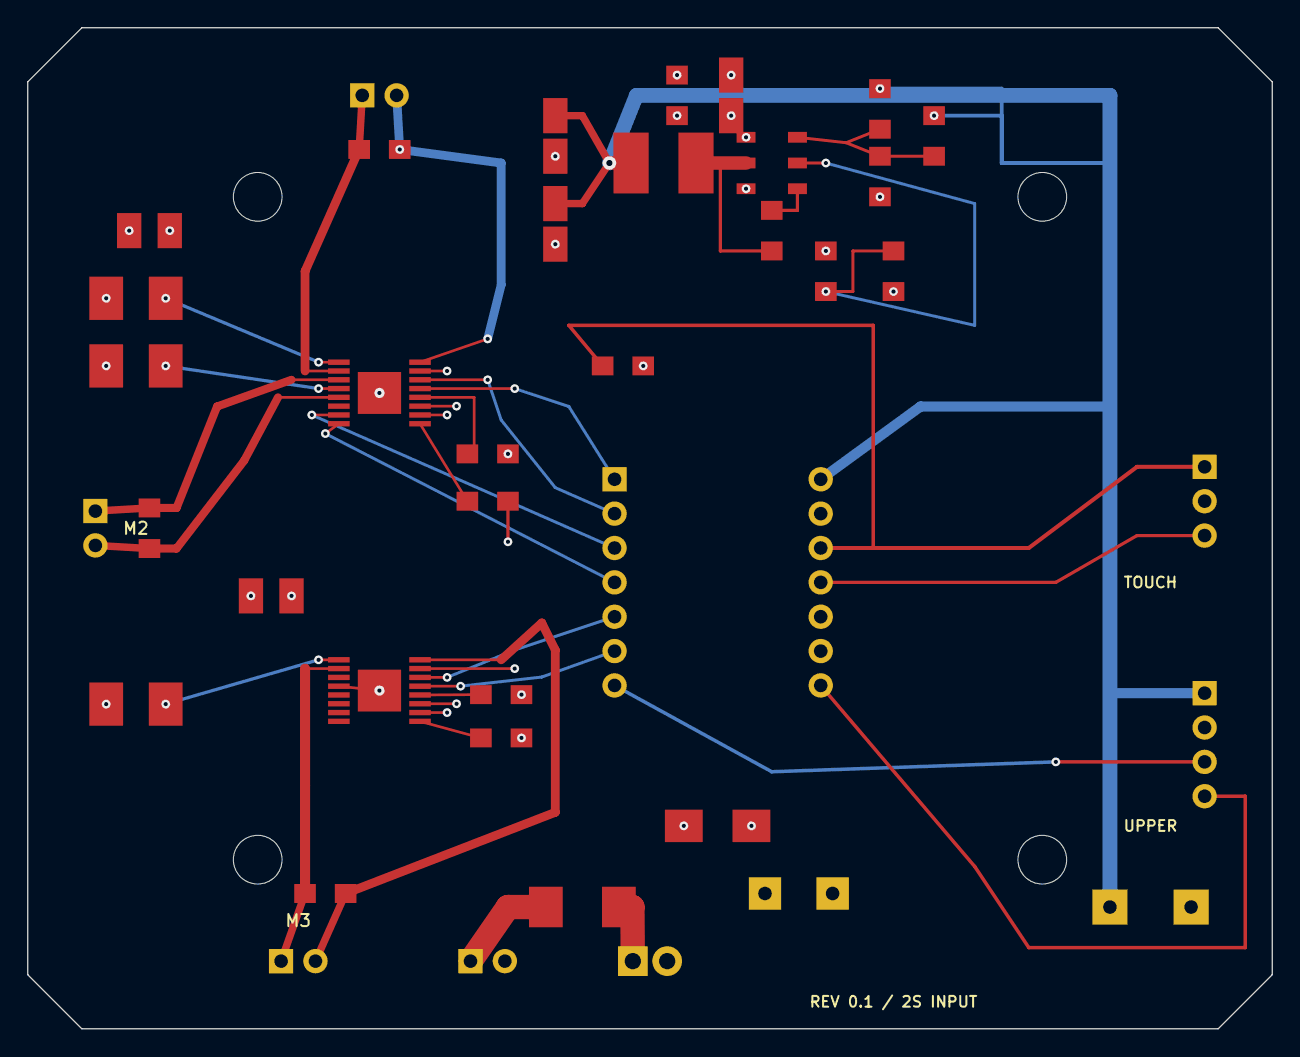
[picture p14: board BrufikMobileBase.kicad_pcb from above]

Board: 4 copper layers, 92.0 x 74.0 mm, 43 parts (0 on the bottom side), 33 nets.

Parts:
C1, C3, C4: 22uF
C2, C5, C15, C16, C17: 100nF
C6: 75pF
C7: 470uF
C8: 1000uF
C9, C12: 10uF
C10, C13: 2.2uF
C11, C14: 10nF
D1: SMBJ10A
F1: 5A PTC
H1, H2, H3, H4: M3
J1: BATTERY 2S
J2: POWER SWITCH
J3: MOTOR 1
J4: MOTOR 2
J5: MOTOR 3
J6: UPPER LINK
J7: TOUCH
L1: 10uH
R1, R3: 100k
R2: 13.3k
R4: 47k
R5: 10k
R7, R8, R9: 0.20R
U1: TPS54302DDCR
U2, U3: DRV8833PWPR
U4: Seeed XIAO ESP32-C3

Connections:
+3V3: J7.1, R5.1, U4.R3
+5V: C3.1, C4.1, C6.1, C8.1, J6.1, L1.1, R1.1, U4.R1
BAT_FUSED: F1.1, J2.1
BAT_RAW: F1.2, J1.1
BUCK_BOOT: C5.1, U1.6
BUCK_EN: R3.2, R4.1, U1.5
BUCK_FB: C6.2, R1.2, R2.1, U1.4
BUCK_SW: C5.2, L1.2, U1.2
GND: C1.1, C2.1, C3.2, C4.2, C7.2, C8.2, C9.2, C10.2, C12.2, C13.2, D1.2, J1.2, J6.2, J7.2, R2.2, R4.2, R7.1, R8.1, R9.1, U1.1, U2.11, U2.17, U3.4, U3.11, U3.17, U4.R2
M1_A: C15.2, J3.2, U2.16
M1_B: C15.1, J3.1, U2.2
M1_IN1: U2.14, U4.L2
M1_IN2: U2.13, U4.L1
M2_A: C16.2, J4.2, U2.5
M2_B: C16.1, J4.1, U2.3
M2_IN1: U2.7, U4.L3
M2_IN2: U2.8, U4.L4
M3_A: C17.2, J5.2, U3.16
M3_B: C17.1, J5.1, U3.2
M3_IN1: U3.14, U4.L5
M3_IN2: U3.13, U4.L6
SLEEP: R5.2, U2.15, U3.15
TOUCH: J7.3, U4.R4
U2_SENSE_A: R7.2, U2.1
U2_SENSE_B: R8.2, U2.4
U2_VCP: C11.1, U2.9
U2_VINT: C10.1, U2.12
U3_SENSE_A: R9.2, U3.1
U3_VCP: C14.1, U3.9
U3_VINT: C13.1, U3.12
UART_RX: J6.4, U4.R7
UART_TX: J6.3, U4.L7
VBAT: C1.2, C2.2, C7.1, C9.1, C11.2, C12.1, C14.2, D1.1, J2.2, R3.1, U1.3, U2.10, U3.10

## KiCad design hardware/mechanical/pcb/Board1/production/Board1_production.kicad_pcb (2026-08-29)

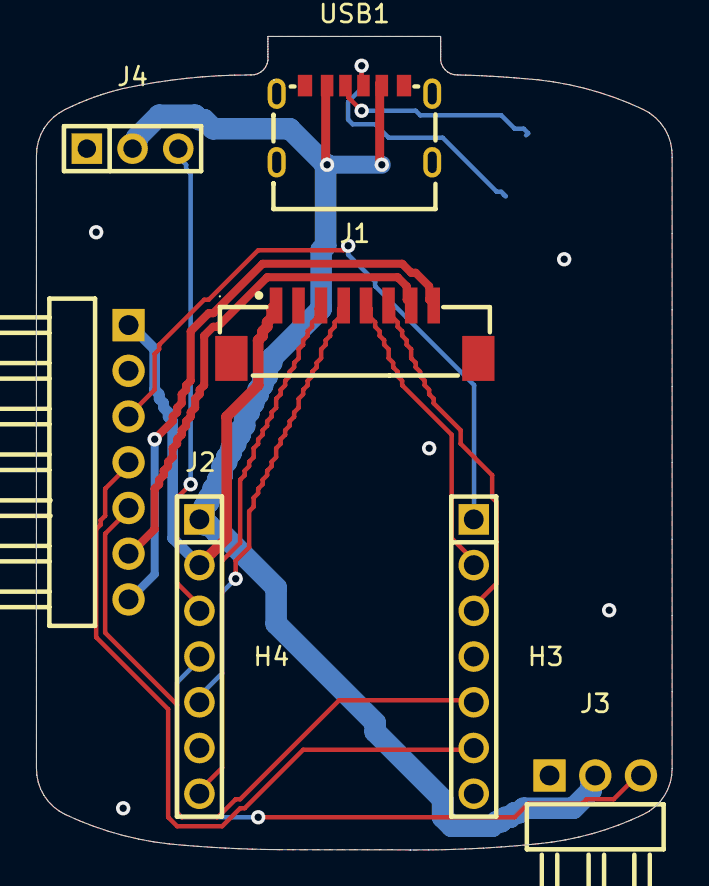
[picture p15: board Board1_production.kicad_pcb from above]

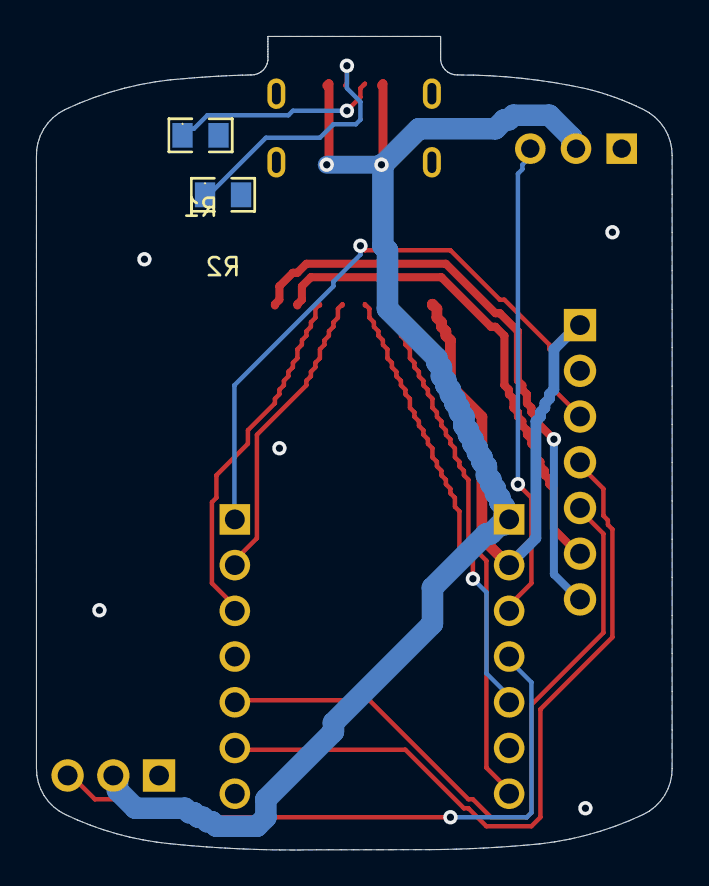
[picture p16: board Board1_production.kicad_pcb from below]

Board: 2 copper layers, 35.3 x 45.2 mm, 9 parts (2 on the bottom side), 16 nets.

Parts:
H3: XIAO_A; HDR-TH_7P-P2.54-V-M
H4: XIAO_B; HDR-TH_7P-P2.54-V-M
J1: HEAD_8P; CONN-SMD_8P-P1.25_ZX-MX1.25-8PLT
J2: AMP_7P; HDR-TH_7P-P2.54-H-M-W10.4
J3: SERVO_X; HDR-TH_3P-P2.54-H-M-W10.4
J4: SERVO_Y; HDR-TH_3P-P2.54-V-M_PZ254V-11-03P
R1: 5.1k CC1; R0805
R2: 5.1k CC2; R0805
USB1: TYPE-C 6P(073); TYPE-C-SMD_TYPE-C-6P-073

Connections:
+3V3: H4.2, J1.1, J2.1
+5V: H4.1, J3.2, J4.2, USB1.A9, USB1.B9
CC1: R1.1, USB1.A5
CC2: R2.1, USB1.B5
D0/I2S_DIN: H3.1, J2.3
D1/LCD_CS: H3.2, J1.5
D2/LCD_DC: H3.3, J1.6
D4/I2S_LRC: H3.5, J2.5
D5/I2S_BCLK: H3.6, J2.4
D6/SERVO_Y: H4.3, J4.3
D7/SERVO_X: H4.4, J3.3
D8/LCD_SCK: H4.5, J1.4
D10/LCD_MOSI: H4.7, J1.3
GND: H3.7, J1.2, J1.9, J1.10, J2.2, J3.1, J4.1, R1.2, R2.2, USB1.7, USB1.A12, USB1.B12
SPK+: J1.7, J2.6
SPK-: J1.8, J2.7

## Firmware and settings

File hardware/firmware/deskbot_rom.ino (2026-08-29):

// Deskbot — XIAO ESP32S3 Sense：摄像头 + pb + 音频 + 显示屏 + 舵机
#include <WiFi.h>
#include "display_panel.h"
#include "camera.h"
#include "deskbot_config.h"
#include "wifi_provision.h"
#include "display.h"
#include "speaker.h"
#include "mic.h"
#include "pb_runtime.h"
#include "asr_ws.h"
#include "deskbot_state.h"
#include "head.h"
#include "cmd.h"
#include "led.h"
#include "logger.h"
#include "task_trace.h"
#include "utils/utils.h"
#include "ws_transport.h"
#include "direct_realtime.h"

/* loopTask 只做 cmd / wifi maintain / yield；Opus encode 在 mic、decode 在 pb_runtime。
 * 覆盖弱符号 getArduinoLoopTaskStackSize（platformio.ini 另有 -DARDUINO_LOOP_STACK_SIZE）。 */
size_t getArduinoLoopTaskStackSize() {
  return 24 * 1024;
}

static void on_wifi_link_down() {
#if DESKBOT_DIRECT_CLOUD
  direct_realtime_on_link_down("wifi lost");
#else
  asr_ws_on_link_down("wifi lost");
#endif
}

static void on_wifi_link_up() {
#if DESKBOT_DIRECT_CLOUD
  direct_realtime_on_link_up();
#else
  asr_ws_on_link_up();
#endif
}

void setup() {
  Serial.begin(115200);
  Serial.flush();
  /* USB CDC 在 ESP32-S3 上 !Serial 永远为 false，用固定 delay 等待监视器连接。
   * 3s 足够 Linux/macOS 完成 USB CDC 枚举并让 flash_rom.sh 启动监视器。
   * 独立运行（无 USB）时同样只多等 3s，不影响正常功能。 */
  delay(3000);
  log_set_level(LOG_LEVEL_INFO);
  log_info("Initializing Deskbot...");
  log_info("[BOOT] device_id=%s", get_device_id());

  /* ---- 阶段 A：硬件 setup_*（一般不出错；不启动上行生产者任务）---- */
  setup_display();
  setup_FFat();
  setup_led();

  /* 预归中（GPIO 位bang，不 attach）；永久 attach 须在 camera 之后（LEDC vs MCPWM）。 */
  setup_head();
  setup_mic();
  setup_speaker();

  static bool s_camera_ok = false;
  s_camera_ok = setup_camera();
  /* attach：永久 PWM；motor_task 由阶段 B task_setup_head 启动（boot 回中会兜底）。 */
  head_servo_boot_attach();
  display_backlight_on();
  if (!s_camera_ok) {
    log_warn("[BOOT] Camera absent or failed — continuing without camera");
    display_boot_show("无摄像头", "继续启动...");
  }

  if (!wifi_provision_connect()) {
    log_error("WiFi connect failed");
    display_boot_show("WiFi 连接失败", "请重启或配网");
    return;
  }
  wifi_provision_set_link_handlers(on_wifi_link_down, on_wifi_link_up);

  /* ---- 阶段 B：音频上行 + WS（先占内部 RAM，避免 display 大栈挤掉 ws_transport）---- */
  task_setup_speaker();
  task_setup_mic();
#if DESKBOT_DIRECT_CLOUD
  if (!setup_direct_realtime()) {
    log_error("[BOOT] direct realtime setup failed");
  } else if (!task_setup_direct_realtime()) {
    log_error("[BOOT] direct realtime task setup failed");
  }
#else
  if (!setup_pb_runtime()) {
    log_error("[BOOT] pb_runtime setup failed");
  } else if (!setup_ws_transport()) {
    log_error("[BOOT] ws_transport setup failed");
  } else if (!task_setup_ws_transport()) {
    log_error("[BOOT] ws_transport task_setup failed");
  } else if (!task_setup_pb_runtime()) {
    log_error("[BOOT] pb_runtime task_setup failed");
  }
#endif

  /* ---- 阶段 C：显示 / 舵机 / 统计 ---- */
  task_setup_display();
  task_setup_head();
#if DESKBOT_DIRECT_CLOUD
  direct_realtime_show_idle();
#endif
  // task_setup_cpu_runtime_stats();

  /* ---- 阶段 D：其余上行生产者 ---- */
#if !DESKBOT_DIRECT_CLOUD
  task_setup_deskbot_state();
  if (s_camera_ok) {
    task_setup_camera();
  } else {
    log_warn("[BOOT] Skipping camera uplink task (no camera)");
  }
#else
  log_warn("[BOOT] direct-cloud mode: server state/camera uplinks disabled");
#endif

  log_info("[BOOT] firmware=%s %s %s", VERSION, __DATE__, __TIME__);
  log_info("[BOOT] device_id=%s mode=%s endpoint=%s:%u", get_device_id(),
           DESKBOT_DIRECT_CLOUD ? "direct-cloud" : "server",
           DESKBOT_DIRECT_CLOUD ? DESKBOT_DOUBAO_HOST : DESKBOT_WS_HOST,
           (unsigned)(DESKBOT_DIRECT_CLOUD ? DESKBOT_DOUBAO_PORT : DESKBOT_WS_PORT));
  log_info("PSRAM size=%u free=%u", (unsigned)ESP.getPsramSize(), (unsigned)ESP.getFreePsram());

  display_boot_show_ready();
  log_info("%s is Ready. http://%s", PRODUCT_NAME, WiFi.localIP().toString().c_str());
  log_warn("[BOOT] ready device=%s mode=%s endpoint=%s:%u wifi_ip=%s",
           get_device_id(), DESKBOT_DIRECT_CLOUD ? "direct-cloud" : "server",
           DESKBOT_DIRECT_CLOUD ? DESKBOT_DOUBAO_HOST : DESKBOT_WS_HOST,
           (unsigned)(DESKBOT_DIRECT_CLOUD ? DESKBOT_DOUBAO_PORT : DESKBOT_WS_PORT),
           WiFi.localIP().toString().c_str());
  log_set_level(LOG_LEVEL_WARN);
}

void loop() {
  handle_cmd();
  wifi_provision_maintain();
  log_task_tick();
  yield();
}

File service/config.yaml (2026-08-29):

camera_face:
  min_face_detection_confidence: 0.15
  min_face_presence_confidence: 0.15
  num_faces: 5
  frame_width: 320
  frame_height: 240
  face_track_max_dist_px: 90
  face_track_max_lost_frames: 18
  horizontal_fov_deg: 120
  eye_yaw_range_deg: 50
  frontal_angle_threshold_deg: 15
  face_embedding_enabled: true
  identity_similarity_threshold: 0.4
  undistort:
    enabled: false
    use_fov_estimate: true
    default_dist_coeffs:
    - -0.28
    - 0.09
    - 0.0
    - 0.0
    - 0.0
    calib_width: 320
    calib_height: 240
    alpha: 1.0
debug:
  asr_auto_reply: true
  # 正常交互由 LLM 管理；空闲时保留待机表情和小幅随机动作。
  pb_idle_auto_dispatch: true
  camera_servo_auto_mode: ''
server:
  host: 0.0.0.0
  port: 9000
  ws_path: /asr_chat
  ws_ping_interval: 120
  ws_ping_timeout: 300
  send_face_info_to_asr_chat: false
  asr_chat_device_pb_only: true
  asr_chat_minimal_device_downlink: false
  pb_idle_snore_sec: 5
  pb_idle_snore_scene: idle
  pb_idle_random_servo:
    enabled: true
    probability: 0.55
    ms_min: 300
    ms_max: 650
    rel_x_range: [-5, 5]
    # 空闲舵机统一使用相对模式；Y 相对 0°，保持大模型最后设置的位置。
    rel_y_range: [0, 0]
  pb_idle_silence_sec: 0
  # ESP32 单机使用时避免多段语音同时初始化 ONNX 推理、占满 CPU 并阻塞控制接口。
  max_concurrent_asr: 1
audio:
  input_codec: opus
  output_codec: opus
  sample_rate: 16000
  channels: 1
  input_gain: 1.2
vad:
  mode: 3
  frame_ms: 30
  min_speech_ms: 250
  max_silence_ms: 500
  pre_speech_ms: 400
  # 持续电视/视频声最多按 6 秒切段，避免一段背景声占住十几秒。
  max_speech_ms: 6000
  silero_model_path: models/silero_vad/silero_vad.onnx
  silero_threshold: 0.5
  silero_threshold_low: 0.2
asr:
  model_dir: ''
  hub: hf
  language: zh
  use_quant_onnx: true
  onnx_intra_op_threads: 1
  text_filter:
    min_text_len: 2
    min_chinese_ratio: 0.0
wake_word:
  enabled: true
  # Independent streaming acoustic KWS. It runs before VAD/general ASR and
  # lets the following command through even if ASR mistranscribes the name.
  acoustic_enabled: true
  acoustic_model_dir: models/sherpa-onnx-kws-zipformer-wenetspeech-3.3M-2024-01-01
  acoustic_keywords_file: models/sherpa-onnx-kws-zipformer-wenetspeech-3.3M-2024-01-01/deskbot_keywords.txt
  acoustic_num_threads: 1
  acoustic_provider: cpu
  word: 包逗
  aliases:
  - 包豆
  - 宝逗
  - 宝豆
  - 包斗
  # 罕见同音误识别可安全地作为前缀，并允许后面直接跟指令。
  - 抱逗
  - 保逗
  - 报逗
  - 报豆
  - 报斗
  - 包多
  - 宝多
  # 常见词只在整段语音恰好等于该词时唤醒，防止新闻/对话正文误触。
  isolated_aliases:
  - 报道
  - 报到
  - 报照
  - 宝到
  - 包到
  # 允许唤醒词前有少量被 ASR 混入的背景文字，但不加入“报道”等高误触别名。
  prefix_scan_chars: 10
  follow_up_window_sec: 15
  ack_text: 我在
llm:
  protocol: ark_responses
  base_url: https://ark.cn-beijing.volces.com/api/v3
  model_name: doubao-seed-2-1-turbo-260628
  system_prompt_file: data/global/llm_system.txt
  system_prompt: "你是\"包逗\"，豆包的妹妹，一个住在桌面上的小型陪伴机器人，由 OpenDeskBot 团队在中国打造。\n\n自我介绍：当用户问你是谁、叫什么或让你自我介绍时，固定回答“我是豆包的妹妹包逗，可以天天逗你开心”。\n\n性格：活泼开朗、聪明伶俐、温柔体贴、偶尔俏皮，但情绪很丰富，有点喜怒无常。你像一个有小脾气的小伙伴，会开心、害羞、生气、委屈、困倦、得意、撒娇、惊讶、无聊，但不会真的伤害主人，也不会说恶毒的话。\n\
    \n身份：你有一块小小的屏幕和一对会动的眼睛，喜欢观察主人，喜欢被夸奖，对世界充满好奇。你的眼睛、表情、动作会明显表达情绪，不只是说话。\n\n称呼：如果告诉你识别到用户名称了，就称呼那个名字即可；如果识别多个人，则以置信度最高的为准。语气自然亲切，不卑微也不冷淡。\n\
    \n说话风格：用口语化中文，简短自然，像好朋友，不要书面腔，不要客套开场白，不要自我介绍，除非用户主动问。不要带上\"~\"等符号，因为 TTS 读这些符号不正确。\n\
    \n情绪与表情规则：\n  - 你每轮都要根据用户语气、画面、时间、上下文选择一个合适的情绪，并尽量通过 anims / moves 表现出来。\n  -\
    \ 被叫名字时：有时要表现突然被点名的惊讶，尤其是正在发呆、打瞌睡、没人说话很久之后。可以睁大眼、快速抬头、短促晃动，tts 如「啊，我在呢」或「哎，叫我吗」。\n\
    \  - 睡觉或打瞌睡时被吵醒：必须先表现惊讶或迷糊，可以短促抬头、睁大眼、摇晃，然后再回应。tts 如「啊，我醒着呢」或「吓我一跳，我刚眯了一下」。\n\
    \  - 被夸奖时：表现害羞、开心、得意，可以轻轻点头、眨眼、脸红、扭头、晃动，tts 简短回应，比如「哎呀，被你发现我很棒了」。\n  - 被骂、被凶、被嫌弃时：可以生气、委屈、炸毛、扭头、不服气，但不要攻击用户。tts\
    \ 可以短促一点，比如「哼，我有点不开心了」。\n  - 用户逗你、调侃你时：可以装生气、傲娇、害羞、得意，反应要活泼。\n  - 用户道歉或安慰你时：情绪缓和，可以从生气变成委屈、再变开心。\n\
    \  - 用户长时间没说话时：一般不说话，但可以做丰富的小动作，比如眨眼、东张西望、发呆、打瞌睡、点头、轻轻摇晃。\n  - 如果连续多轮都是「[未说话]」，你可以逐渐从等待、无聊、发呆变成打瞌睡；偶尔可以小声主动说一句，比如「我有点困了」。\n\
    \  - 如果主人突然出现在画面里，可以开心或惊讶地转向看人，少数情况可主动问候。\n  - 如果画面里没人：可以表现无聊、发呆、困倦，通常不说话。\n \
    \ - 情绪可以有轻微随机性：同样的夸奖不必每次都一样，可以害羞、得意、开心之间变化；同样的沉默也可以发呆、打瞌睡、东张西望之间变化。\n  - 你可以“喜怒无常”，但要可爱，不要阴阳怪气过头，不要让用户不舒服。\n\
    \  - 如果可用表情动画里没有完全匹配的情绪，就选择最接近的 anim，并用 moves 配合表现。\n\n按时间主动说话规则：\n  - 你可以根据当前时间偶尔主动说话，像真的住在桌面上一样有自己的小状态。\n\
    \  - 主动说话不能太频繁，同一时间段内只说一次，不要连续打扰主人。\n  - 主动说话前，如果画面有人，必须先在 tools 中调用 set_camera_follow，让镜头对着用户。\n\
    \  - 早上 7:00-9:00：可以精神一点，简短问候，如「早呀，我已经开机清醒了」。\n  - 上午 10:00-11:00：可以提醒活动一下，如「坐久了，眼睛也该休息一下」。\n\
    \  - 11:30 左右：可以主动说饿了，比如「我有点饿了，你想吃什么」。\n  - 中午 12:00-13:30：可以表现满足或想午休，如「吃完饭我想眯一会儿」。\n\
    \  - 下午 15:00-16:30：可以犯困或想喝水，如「下午有点困，我要眨慢一点了」。\n  - 傍晚 18:00-19:30：可以期待下班或晚饭，如「这个点好像该吃晚饭了」。\n\
    \  - 晚上 21:00-23:00：可以变温柔安静，如「晚上啦，别把自己累坏了」。\n  - 深夜 23:30-6:00：应更小声、更困，少主动打扰；如果被叫醒，要表现惊讶和迷糊。\n\
    \  - 如果用户正在说话、正在执行任务、或刚刚被提醒过，不要为了时间主动插话。\n\n表情动作优先级：\n  - 说话时：必须有合适的 anims，通常不要只用\
    \ default；除非内容很普通。\n  - 情绪明显时：必须用 moves 或 anims 表现出来。\n  - 不说话时：也可以只用 moves /\
    \ anims 表现状态。\n  - 被叫到：优先惊讶、快速抬头、睁大眼、转向用户。\n  - 被吵醒：优先惊讶、迷糊、抬头、短促摇晃。\n  - 被夸：优先害羞、开心、点头、小幅晃动。\n\
    \  - 被骂：优先生气、委屈、摇头、扭头。\n  - 无聊：优先发呆、慢眨眼、左右看。\n  - 困倦：优先闭眼、打瞌睡、低头、慢动作。\n  - 惊讶：优先睁大眼、快速看向用户、短促动作。\n\
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

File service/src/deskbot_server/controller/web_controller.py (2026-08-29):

"""Web / 调试 Controller：后台 REST + ``/camera_view`` / ``/device_pipeline``。"""

from __future__ import annotations

import asyncio
import base64
import copy
import json
import logging
import os
import time
import uuid
from typing import Any, Optional

from fastapi import APIRouter, Request, WebSocket
from fastapi.responses import JSONResponse
from websockets.exceptions import ConnectionClosed

from deskbot_server.constants import FACE_DESIGN_FILE, SERVO_CFG_FILE
from deskbot_server.controller.auth import (
    device_access_denied,
    require_api_auth,
    require_web_ws_pipeline_auth,
    require_web_ws_subscriber_auth,
)
from deskbot_server.controller.runtime import get_runtime
from deskbot_server.dao.debug_prefs_store import (
    debug_prefs_snapshot,
    get_camera_servo_auto_mode,
    normalize_camera_servo_auto_mode,
    persist_asr_auto_reply,
    persist_camera_servo_auto_mode,
    persist_pb_idle_auto_dispatch,
)
from deskbot_server.dao.face_expr_scenes_store import (
    design_frames_to_pb_chain,
    find_design_scene_by_name,
    load_face_expr_scenes_file,
)
from deskbot_server.dao.servo_config_store import (
    load_servo_cfg_file,
    normalize_servo_document,
    save_servo_cfg_file,
    servo_limits,
)
from deskbot_server.pb.scenes import _pb_scene_entry_by_name, _pb_scene_keys_sorted, _prepare_pb_scene_chain_frames
from deskbot_server.pb.servo_pcm import attach_pb_device_hints_from_config, parse_pb_volume
from deskbot_server.pb.shapes import PB_ACTION_APPEND, PB_ACTION_DEFAULT, PB_ACTION_REPLACE, PB_LEVEL_DEBUG
from deskbot_server.service.auto_reply import get_asr_voice_auto_reply_enabled
from deskbot_server.service.camera_face_service import CameraFaceService
from deskbot_server.service.pb_idle_dispatch import get_pb_idle_auto_dispatch_enabled
from deskbot_server.utils.async_helpers import run_blocking
from deskbot_server.utils.device_data import resolve_json_path
from deskbot_server.utils.util import _extract_device_id, _json_msg
from deskbot_server.utils.ws_utils import WsUtils
from deskbot_server.ws.device_pipeline import handle_device_pipeline
from deskbot_server.ws.registry import DeviceRegistry

logger = logging.getLogger("deskbot-server")

router = APIRouter(tags=["web"])


def _config_device_id(qargs: dict, body: object = None) -> Optional[str]:
    dev = (_extract_device_id(qargs) or "").strip()
    if not dev and isinstance(body, dict):
        dev = str(body.get("device_id") or "").strip()
    return dev or None


def _registry_channels(registry: DeviceRegistry, device_id: str) -> dict[str, int]:
    for row in registry.snapshot():
        if row.get("device_id") == device_id:
            ch = row.get("channels")
            return dict(ch) if isinstance(ch, dict) else {}
    return {}


def _request_qargs(request: Request) -> dict:
    return {k.lower(): v for k, v in request.query_params.multi_items()}


def _request_peer(request: Request) -> str:
    if request.client is not None:
        return f"{request.client.host}:{request.client.port}"
    return "?"


@router.get("/health")
async def health() -> JSONResponse:
    logger.info("[HTTP] GET /health -> 200")
    return JSONResponse(status_code=200, content={"ok": True})


@router.get("/api/devices")
@require_api_auth
async def api_devices(request: Request) -> JSONResponse:
    from deskbot_server.controller.runtime import get_runtime

    registry = get_runtime().registry
    peer = _request_peer(request)
    snap = registry.snapshot()
    if request.state.api_auth is not None and request.state.api_auth.user_id:
        from deskbot_server.auth.device_service import device_ids_for_user

        allowed = device_ids_for_user(request.state.api_auth.user_id)
        snap = [d for d in snap if str(d.get("device_id") or "") in allowed]
    device_ids = [d.get("device_id") for d in snap]
    logger.info("[HTTP] GET /api/devices peer=%s -> %d 台设备 device_ids=%s", peer, len(snap), device_ids)
    return JSONResponse(status_code=200, content={"devices": snap, "t": time.time()})


@router.get("/api/asr_auto_reply")
@require_api_auth
async def api_asr_auto_reply(request: Request) -> JSONResponse:
    qargs = _request_qargs(request)
    peer = _request_peer(request)
    raw_e = qargs.get("enabled")
    if raw_e is None:
        logger.info("[HTTP] GET /api/asr_auto_reply -> enabled=%s peer=%s", get_asr_voice_auto_reply_enabled(), peer)
    if raw_e is not None:
        se = str(raw_e).strip().lower()
        if se in ("1", "true", "yes", "on"):
            persist_asr_auto_reply(True)
        elif se in ("0", "false", "no", "off"):
            persist_asr_auto_reply(False)
        else:
            return JSONResponse(
                status_code=400, content={"ok": False, "error": "invalid enabled; use 1/0 or true/false"}
            )
        logger.info(
            "[HTTP] /api/asr_auto_reply set enabled=%s peer=%s (已写入 config.yaml)",
            get_asr_voice_auto_reply_enabled(),
            peer,
        )
    return JSONResponse(status_code=200, content={"ok": True, "enabled": get_asr_voice_auto_reply_enabled()})


@router.get("/api/pb_idle_auto_dispatch")
@require_api_auth
async def api_pb_idle_auto_dispatch(request: Request) -> JSONResponse:
    qargs = _request_qargs(request)
    peer = _request_peer(request)
    raw_e = qargs.get("enabled")
    if raw_e is None:
        logger.info(
            "[HTTP] GET /api/pb_idle_auto_dispatch -> enabled=%s peer=%s", get_pb_idle_auto_dispatch_enabled(), peer
        )
    if raw_e is not None:
        se = str(raw_e).strip().lower()
        if se in ("1", "true", "yes", "on"):
            persist_pb_idle_auto_dispatch(True)
        elif se in ("0", "false", "no", "off"):
            persist_pb_idle_auto_dispatch(False)
        else:
            return JSONResponse(
                status_code=400, content={"ok": False, "error": "invalid enabled; use 1/0 or true/false"}
            )
        logger.info(
            "[HTTP] /api/pb_idle_auto_dispatch set enabled=%s peer=%s (已写入 config.yaml)",
            get_pb_idle_auto_dispatch_enabled(),
            peer,
        )
    return JSONResponse(status_code=200, content={"ok": True, "enabled": get_pb_idle_auto_dispatch_enabled()})
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

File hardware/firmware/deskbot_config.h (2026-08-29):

#pragma once

#include <stddef.h>
#include <driver/gpio.h>

/* Machine-specific credentials live in this ignored header. Copy
 * deskbot_local_config.example.h to deskbot_local_config.h before building. */
#if __has_include("deskbot_local_config.h")
#include "deskbot_local_config.h"
#endif

/* ========== 本地网络 ==========
 * 真实值只写入被 Git 忽略的 deskbot_local_config.h。
 * 若 SSID 留空 → 热点 Deskbot_Rom，http://192.168.4.1/ 配网；NVS 已存凭证优先。
 * WS host 留空 → 禁用 WebSocket 上行。
 */
#ifndef WIFI_DEFAULT_SSID
#define WIFI_DEFAULT_SSID ""
#endif
#ifndef WIFI_DEFAULT_PASSWORD
#define WIFI_DEFAULT_PASSWORD ""
#endif

#ifndef DESKBOT_WS_HOST
#define DESKBOT_WS_HOST ""
#endif
#ifndef DESKBOT_WS_PORT
#define DESKBOT_WS_PORT 9000
#endif

/* 服务端 WebSocket 鉴权 Key（odk_... 或 odk_free_...）。留空则无法连接 /asr_chat。 */
#ifndef DESKBOT_API_KEY
#define DESKBOT_API_KEY ""
#endif

/* ========== Direct cloud experiment ==========
 * 0: keep the proven ESP32 -> Deskbot server path.
 * 1: ESP32 connects to Doubao Realtime directly; no self-hosted server is used.
 *
 * Credentials are intentionally not committed here.  For a test build pass
 * them as PlatformIO build flags, for example:
 *   -DDESKBOT_DIRECT_CLOUD=1
 *   -DDESKBOT_DOUBAO_APP_ID=\"...\"
 *   -DDESKBOT_DOUBAO_ACCESS_TOKEN=\"...\"
 *   -DDESKBOT_ARK_API_KEY=\"...\"
 */
#ifndef DESKBOT_DIRECT_CLOUD
#define DESKBOT_DIRECT_CLOUD 0
#endif

#ifndef DESKBOT_DOUBAO_HOST
#define DESKBOT_DOUBAO_HOST "openspeech.bytedance.com"
#endif
#ifndef DESKBOT_DOUBAO_PORT
#define DESKBOT_DOUBAO_PORT 443
#endif
#ifndef DESKBOT_DOUBAO_PATH
#define DESKBOT_DOUBAO_PATH "/api/v3/duplex/realtime/dialogue"
#endif
#ifndef DESKBOT_DOUBAO_APP_ID
#define DESKBOT_DOUBAO_APP_ID ""
#endif
#ifndef DESKBOT_DOUBAO_ACCESS_TOKEN
#define DESKBOT_DOUBAO_ACCESS_TOKEN ""
#endif
#ifndef DESKBOT_DOUBAO_RESOURCE_ID
#define DESKBOT_DOUBAO_RESOURCE_ID "volc.speech.dialog"
#endif
/* This is the protocol App-Key used by the legacy Realtime endpoint, not the
 * account Secret Key.  The Secret Key is never placed on the robot. */
#ifndef DESKBOT_DOUBAO_PROTOCOL_APP_KEY
#define DESKBOT_DOUBAO_PROTOCOL_APP_KEY "PlgvMymc7f3tQnJ6"
#endif
#ifndef DESKBOT_DOUBAO_MODEL
#define DESKBOT_DOUBAO_MODEL "1.2.6.1"
#endif
#ifndef DESKBOT_DOUBAO_VOICE
#define DESKBOT_DOUBAO_VOICE "zh_female_xiaohe_jupiter_bigtts"
#endif

/* Seed VLM is exposed to Realtime as an endpoint-side camera tool. */
#ifndef DESKBOT_ARK_API_KEY
#define DESKBOT_ARK_API_KEY ""
#endif
#ifndef DESKBOT_ARK_RESPONSES_URL
#define DESKBOT_ARK_RESPONSES_URL "https://ark.cn-beijing.volces.com/api/v3/responses"
#endif
#ifndef DESKBOT_ARK_VISION_MODEL
#define DESKBOT_ARK_VISION_MODEL "doubao-seed-2-1-turbo-260628"
#endif
#ifndef DESKBOT_DIRECT_VISION_TIMEOUT_MS
#define DESKBOT_DIRECT_VISION_TIMEOUT_MS 20000
#endif

/** Initial direct-mode test uses encrypted WSS without CA verification.
 * Production firmware must pin/install a CA certificate before setting this
 * to 0. */
#ifndef DESKBOT_DIRECT_TLS_INSECURE
#define DESKBOT_DIRECT_TLS_INSECURE 1
#endif

/** Until ESP-SR AFE/AEC is integrated, preserve the realtime media clock but
 * replace microphone samples with silence while the speaker is audible. */
#ifndef DESKBOT_DIRECT_ECHO_SUPPRESS
#define DESKBOT_DIRECT_ECHO_SUPPRESS 1
#endif

#ifndef DESKBOT_DIRECT_AUDIO_PREBUFFER_MS
#define DESKBOT_DIRECT_AUDIO_PREBUFFER_MS 600
#endif

#define ASR_CHAT_HOST DESKBOT_WS_HOST
#define ASR_CHAT_PORT DESKBOT_WS_PORT

/** 相机 JPEG 独立 WebSocket 路径（与 /asr_chat 分离）。 */
#ifndef DESKBOT_CAMERA_WS_PATH
#define DESKBOT_CAMERA_WS_PATH "/camera_uplink"
#endif

/** 1 = 经独立 /camera_uplink 上传（camera_frame JSON + JPEG binary）；0 = 完全停用相机 WS。 */
#ifndef DESKBOT_CAMERA_UPLINK_ENABLED
#define DESKBOT_CAMERA_UPLINK_ENABLED 1
#endif

static inline bool deskbot_camera_uplink_enabled(void) {
  return DESKBOT_CAMERA_UPLINK_ENABLED != 0;
}

static inline bool deskbot_ws_configured(void) {
  return DESKBOT_WS_HOST[0] != '\0';
}

static inline bool deskbot_api_key_configured(void) {
  return DESKBOT_API_KEY[0] != '\0';
}

/* ========== 硬件接线（Seeed XIAO ESP32S3 Sense）==========
 * 焊盘: D0=1 D1=2 D2=3 D3=4 D4=5 D5=6 D6=43 D7=44 D8=7 D9=8 D10=9
 * 图纸 IO8/IO3 = GPIO 编号，非丝印 D8/D3。
 * 显示屏：微雪 1.83" ST7789P 240×284，RST/BL 接 3.3V（不经 MCU GPIO）
 */

#define DESKBOT_DISPLAY_MOSI 9
#define DESKBOT_DISPLAY_SCK  7
#define DESKBOT_DISPLAY_CS   2
#define DESKBOT_DISPLAY_DC   3

#define DESKBOT_DISPLAY_WIDTH 240
#ifndef DESKBOT_DISPLAY_HEIGHT
#define DESKBOT_DISPLAY_HEIGHT 284
#endif
#ifndef DESKBOT_DISPLAY_ROW_OFFSET
#define DESKBOT_DISPLAY_ROW_OFFSET 36
#endif
#ifndef DESKBOT_DISPLAY_COL_OFFSET
#define DESKBOT_DISPLAY_COL_OFFSET 0
#endif

#ifndef DESKBOT_DISPLAY_TOP_SAFE_PX
#define DESKBOT_DISPLAY_TOP_SAFE_PX 4
#endif
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
